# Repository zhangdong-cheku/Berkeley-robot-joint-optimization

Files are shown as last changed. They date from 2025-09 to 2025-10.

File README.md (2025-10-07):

# Berkeley robot joint optimization - 高性能摆线减速器

##  点击图片查看视频
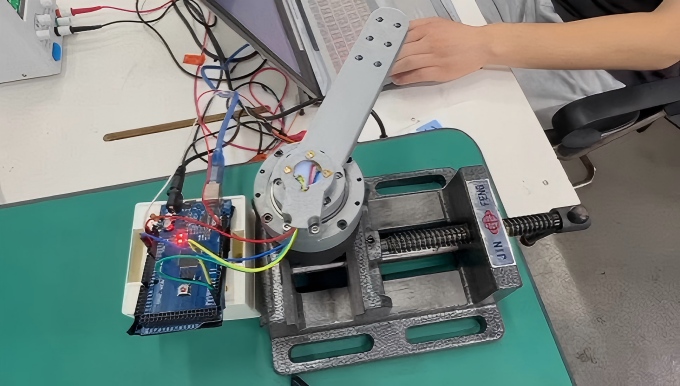
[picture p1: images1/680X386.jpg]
青潮智科 (UntHub) 视频介绍 (https://www.bilibili.com/video/BV1g6nszREnb)


---

##  项目概述
**CycloidalReducer100** 是伯克利开源机器人项目中的摆线传动方案，进行深度优化与复刻的高精度减速器。它采用经典的摆线针轮啮合原理，具备**高扭矩密度、零背隙、长寿命**等优点，专为机器人关节、精密转台、自动化设备等对传动性能要求极高的场景设计。

项目目标是为开源社区和工业界提供一个可靠、高性能、易于获取的减速器解决方案，推动先进机器人的创新与普及。

---

##  核心特性
*   **高精度与零背隙**：精密的齿形优化与制造工艺，确保传动平稳，定位精准。
*   **高扭矩密度**：紧凑的结构设计，在狭小空间内实现大的输出扭矩。
*   **高刚性 & 抗冲击**：多齿同时啮合，承载能力强，适用于高动态负载场景。
*   **长寿命与高可靠性**：关键部件采用高强度轴承钢并经特殊热处理，耐磨性好。
---

##  技术规格
| 参数 | 数值/描述 | 单位/备注 |
| :--- | :--- | :--- |
| **型号** | Berkeley robot joint | - |
| **额定输出扭矩** | 100 | N·m |
| **峰值扭矩** | 300 | N·m |
| **减速比** | 11, 17, 23, 29, 35, 43, 59, 71, 87 | 可选 |
| **背隙** | ≤ 5 | arcmin (标准型) |
| **输入转速** | ≤ 3000 | rpm |
| **效率** | ≥ 90% | - |
| **重量** | ≈ 8.5 | kg |
| **防护等级** | IP65 | - |
| **安装方式** | 法兰安装 | - |

---

## 项目展示

### 1. 整体外观
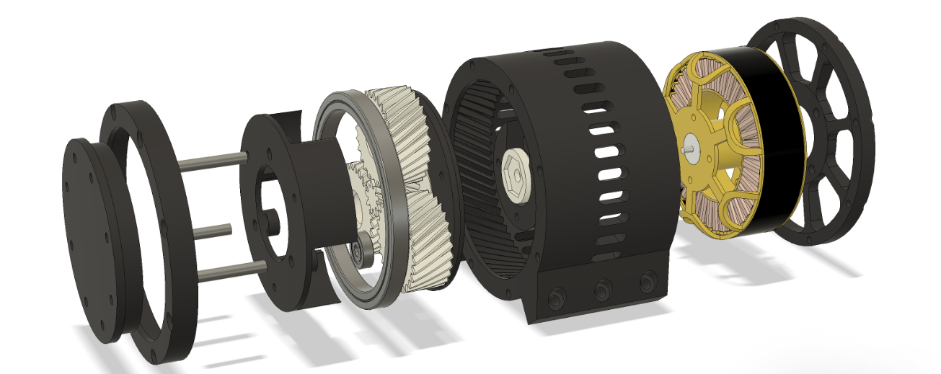
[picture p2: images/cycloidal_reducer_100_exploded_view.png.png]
Berkeley robot joint optimization爆炸视图
<!-- 请替换为实际图片路径，并提供 alt 文本 -->
*图：Berkeley robot joint optimization 整机装配体，展现了紧凑的设计与精湛的工艺。*

 <!--2. 爆炸视图-->
 <!--![爆炸视图](images/cycloidal_reducer_100_exploded_view.png.png) --><!-- 请替换为实际图片路径 -->
 <!--*图：减速器爆炸视图，清晰展示所有内部零件及其装配关系。*-->

 <!--3. 应用场景-->
<!--  ![机器人关节应用](images/reducer_in_robot_arm.jpg)--> <!-- 请替换为实际图片路径 -->
<!-- 图：CycloidalReducer100 应用于六轴工业机器人关节模组。*-->

---

##  安装与使用

### 环境准备
*   3D 建模软件（如 **SolidWorks**, **Fusion 360**）用于查看模型。
*   机械装配工具（扭矩扳手、螺丝刀套装等）。

### 安装步骤
1.  **获取模型**：

模型文件位于 `models/` 目录下（提供 STEP 和 SLDPRT 格式）。

2.  **机械安装**：
*   确保安装面平整清洁。
*   使用规定的螺栓（如 M8）和扭矩（**80 N·m**）紧固。
*   保证输入轴与驱动电机轴、输出轴与负载轴的**同轴度**（建议 ≤ 0.03mm）。

3.  **润滑**：
*   首次使用前，加注适量的 **ISO VG 220** 工业齿轮油至油窗中线。
*   每运行 2000 小时或一年后更换润滑油。

## 加入交流群
扫一扫，加入QQ群，一起手搓机器人

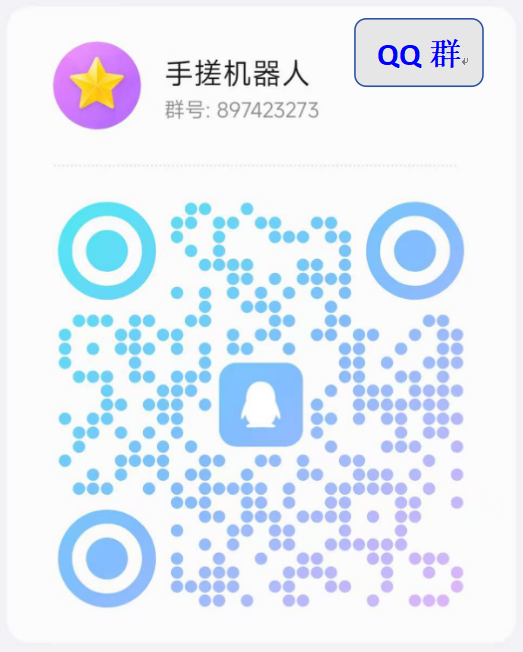
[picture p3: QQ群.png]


---

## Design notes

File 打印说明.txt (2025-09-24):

1.3D打印机推荐：：拓竹系列参数的匹配性。
2.打印材料：采用pla3D材料。
3.打印参数，使用拓竹系列打印机默认配置，填充密度50%-60%，摆线轮、行星轮可填充至70%，太阳轮可填充至80%。

***注意：solidworks文件导出，以step格式导出，减少层纹出现，减少摩擦，可购买（虎头0号润滑脂）提高降速机寿命。

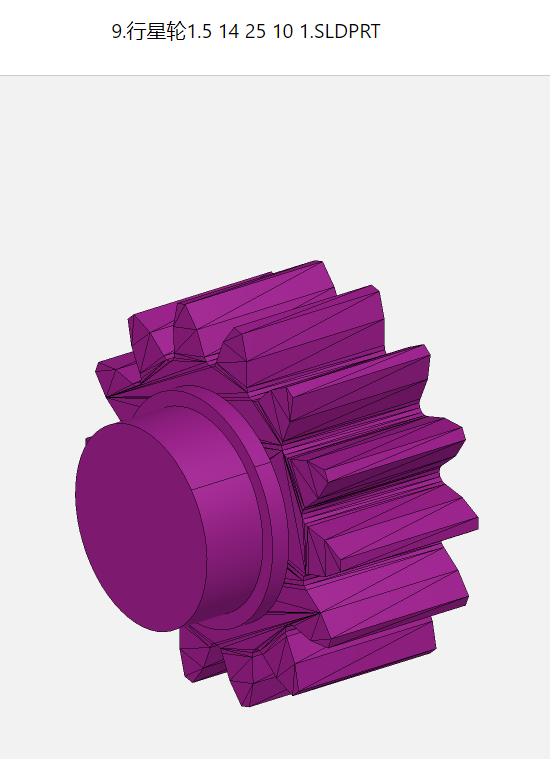
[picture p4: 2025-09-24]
images/8.行星轮1.5 14 25 10 1.png

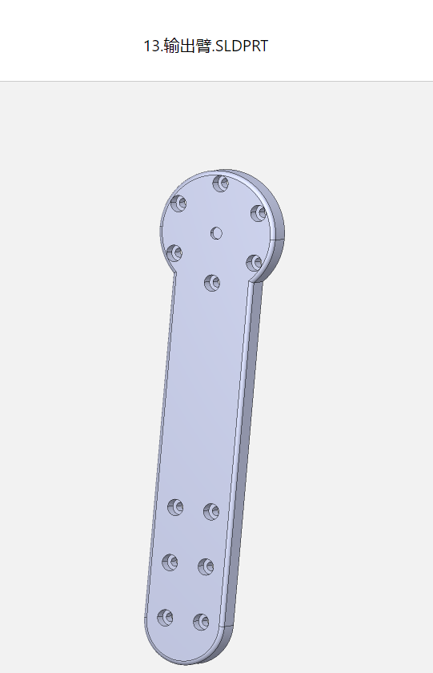
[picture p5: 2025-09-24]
images/12.输出臂.png

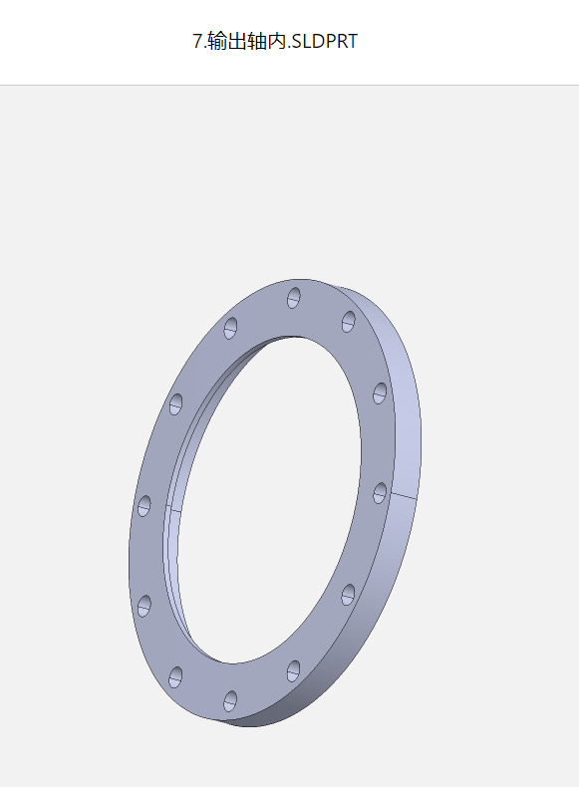
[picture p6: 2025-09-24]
images/6.输出轴内.png

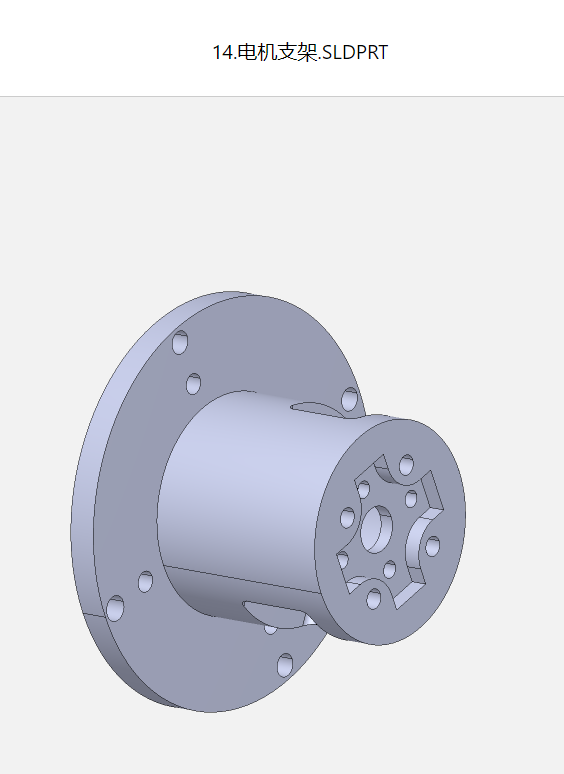
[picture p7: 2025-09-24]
images/13.电机支架.png

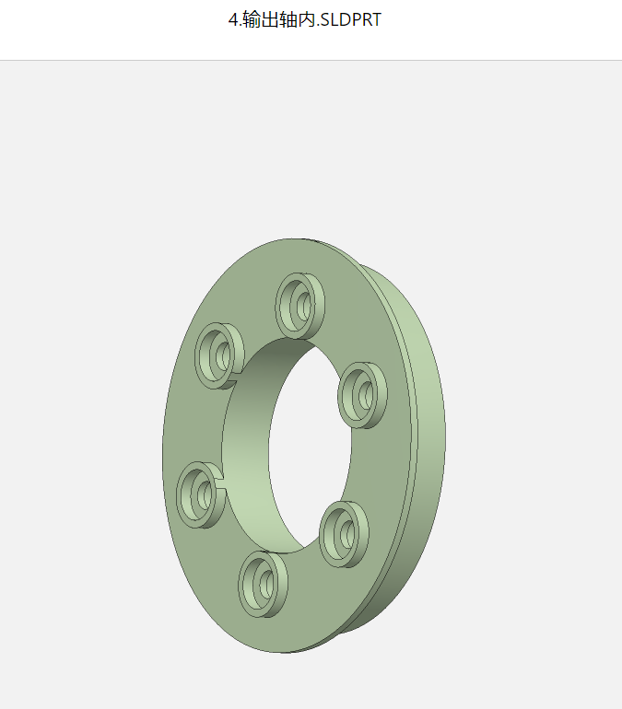
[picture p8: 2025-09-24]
images/3.输出轴内.png

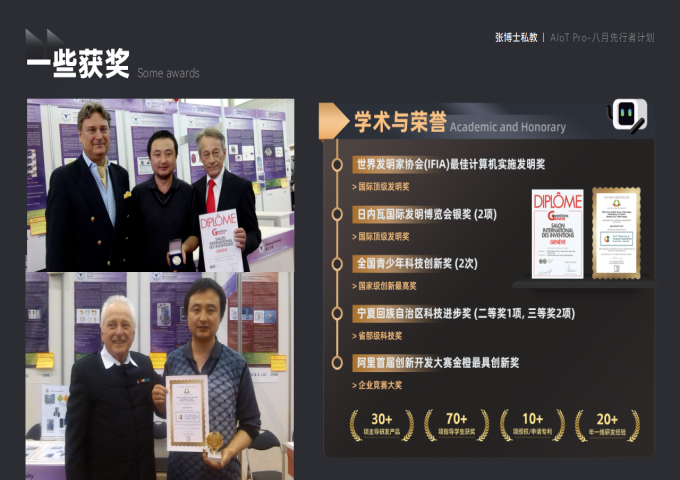
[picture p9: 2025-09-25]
images/team/250c74cfa8658368c13a1646a05376d6.png

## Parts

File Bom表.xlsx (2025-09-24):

70.115行星摆线减速机BOM/结构部分
名称 | 型号 | 数量 | 单价/元 | 总价 | 备注 | 链接
轴承 | MR106-2RS | 13 | 1.44 | 18.72 | 内径8外径10mm两侧密封 | https://detail.tmall.com/item.htm?id=850288392637&skuId=5639536048009&spm=a21m98.27004841
轴承 | MR106-2RS | 5 | 1.84 | 9.2 | 内径12外径18mm两侧密封 | https://detail.tmall.com/item.htm?abbucket=9&id=672836796497&skuId=5017505094887
轴承 | 6809ZZ | 2 | 3.11 | 6.22 | 两侧密封 | https://detail.tmall.com/item.htm?abbucket=8&id=695287603935&ns=1&skuId=5102438922481
螺钉 | M3*55mm | 10 | 0.3 | 3 |  | https://detail.tmall.com/item.htm?abbucket=8&id=654819932601
螺钉 | M3*25mm | 50 | 0.066 | 3.3 |  | https://detail.tmall.com/item.htm?abbucket=8&id=654819932601&skuId=5014407101291
螺钉 | M3*16mm | 100 | 0.05 | 5 |  | https://detail.tmall.com/item.htm?abbucket=8&id=654819932601&skuId=4732319681183
螺钉 | M3*8mm | 100 | 0.04 | 4 |  | https://detail.tmall.com/item.htm?abbucket=8&id=654819932601&skuId=4732319681175
热熔螺母 | M3*4*5 | 100 | 0.13 | 13 |  | https://item.taobao.com/item.htm?id=593581996419&skuId=4189077672129
六角铜隔离柱 | M4*12 | 10 | 0.333 | 3.33 |  | https://detail.tmall.com/item.htm?abbucket=8&id=645528391157&skuId=4641513876088

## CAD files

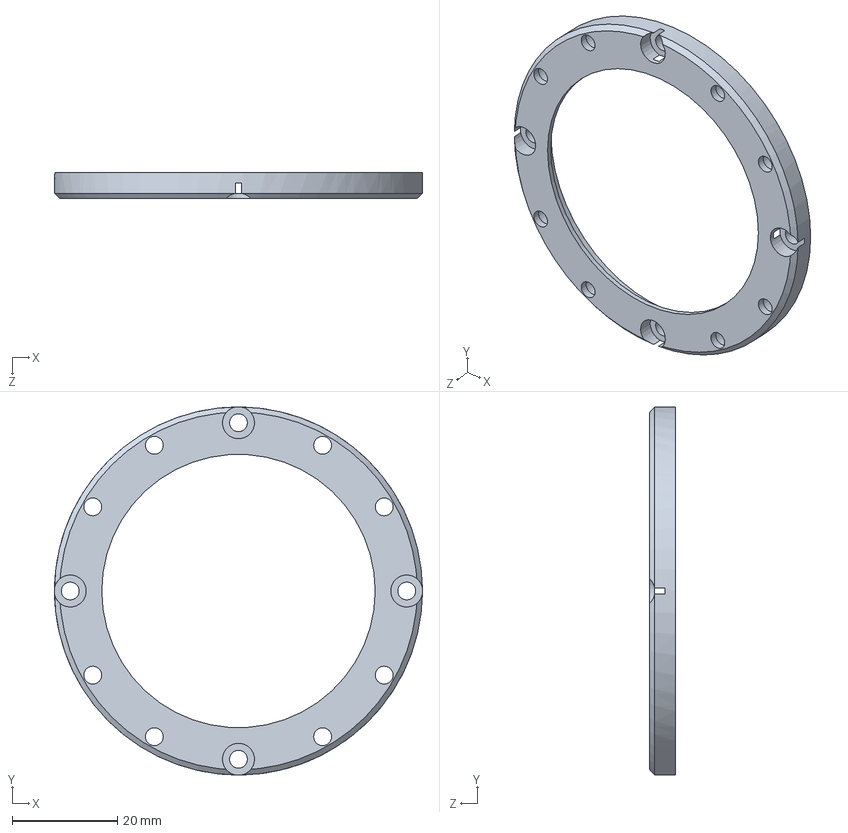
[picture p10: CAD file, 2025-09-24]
STL/5.针齿壳外.SLDPRT
70.0 x 70.0 x 5.00 mm

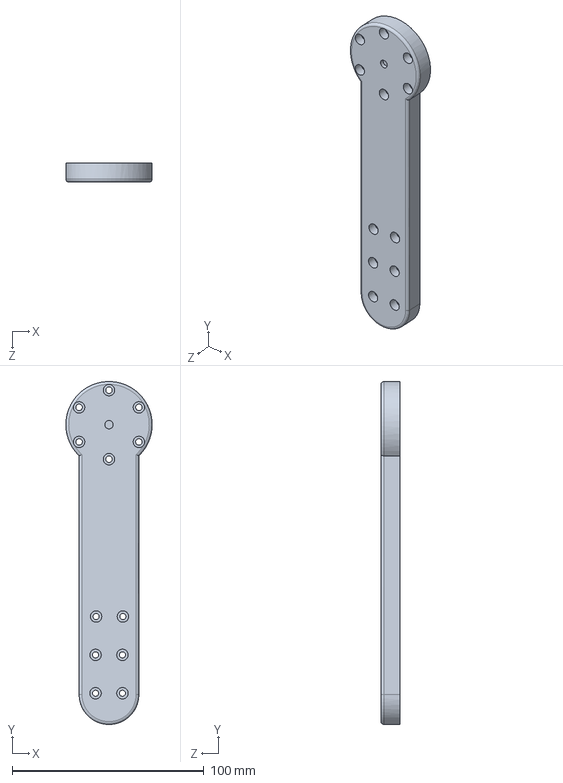
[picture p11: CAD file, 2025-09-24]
STL/13.输出臂.SLDPRT
45.0 x 178.8 x 10.0 mm

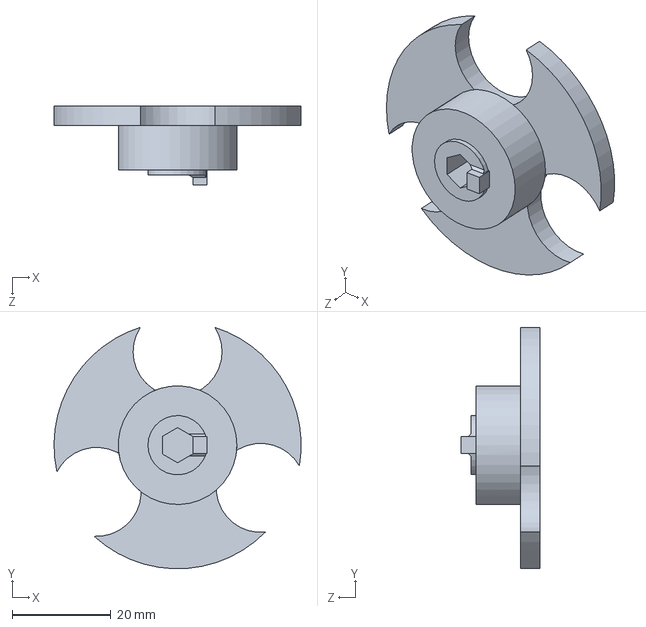
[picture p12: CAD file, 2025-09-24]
STL/8.行星支架.SLDPRT
50.0 x 48.8 x 16.0 mm

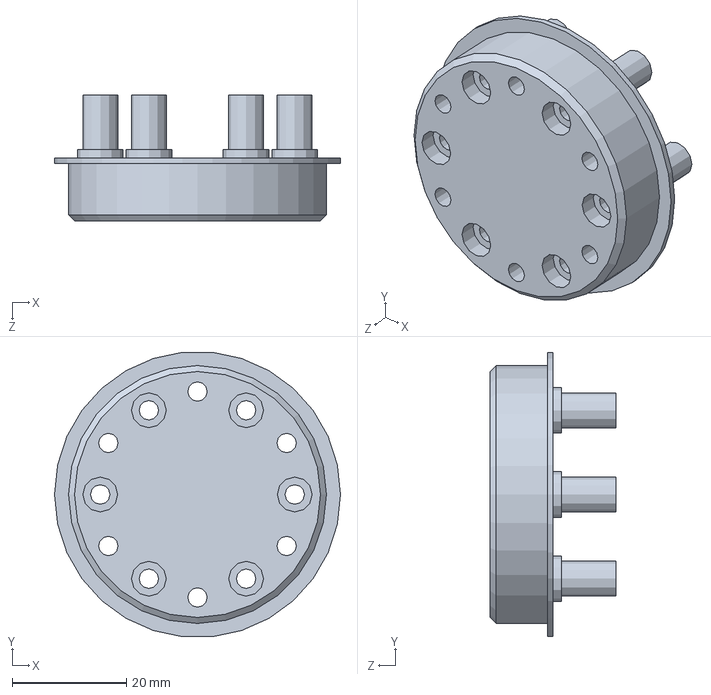
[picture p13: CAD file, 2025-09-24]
STL/1.输出轴外.SLDPRT
50.0 x 49.7 x 22.0 mm

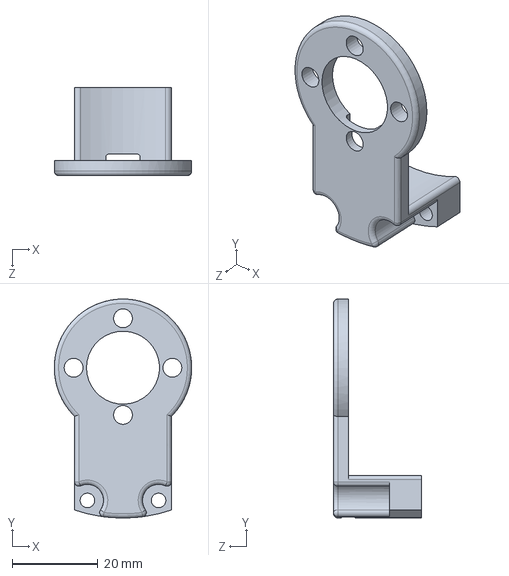
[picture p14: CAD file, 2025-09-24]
STL/12.角度支架.SLDPRT
32.0 x 51.0 x 20.5 mm

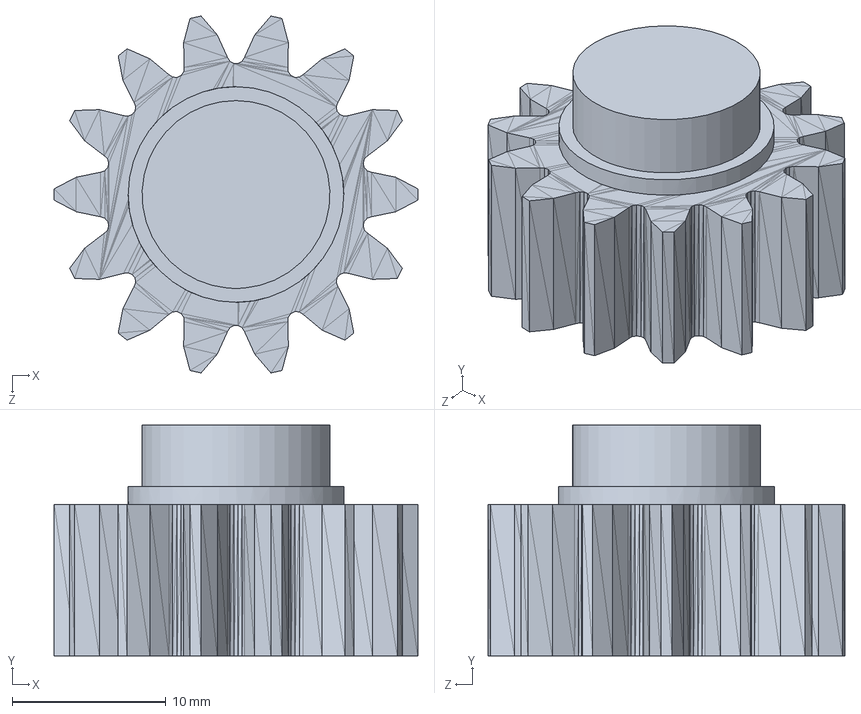
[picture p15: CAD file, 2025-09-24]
STL/9.行星轮1.5 14 25 10 1.SLDPRT
23.6 x 15.0 x 23.2 mm

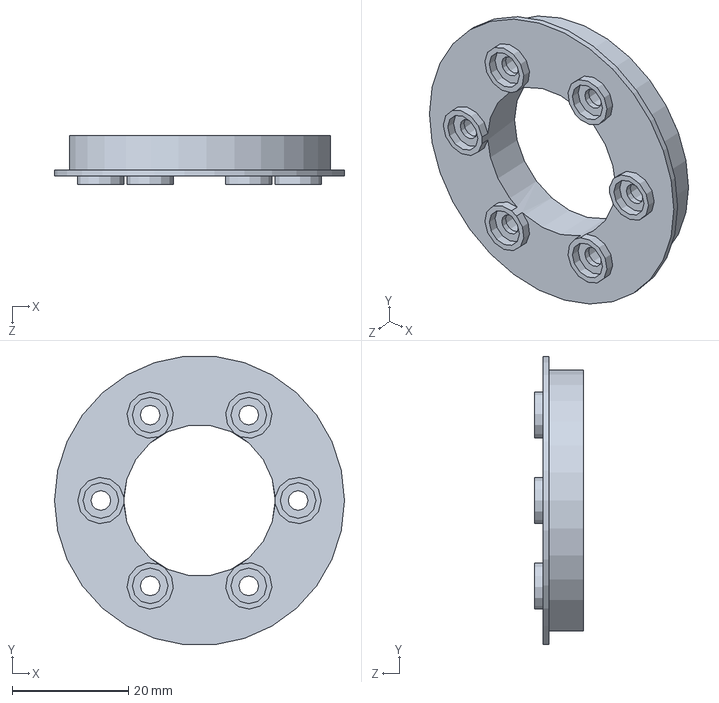
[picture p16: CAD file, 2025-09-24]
STL/4.输出轴内.SLDPRT
50.0 x 49.7 x 8.50 mm

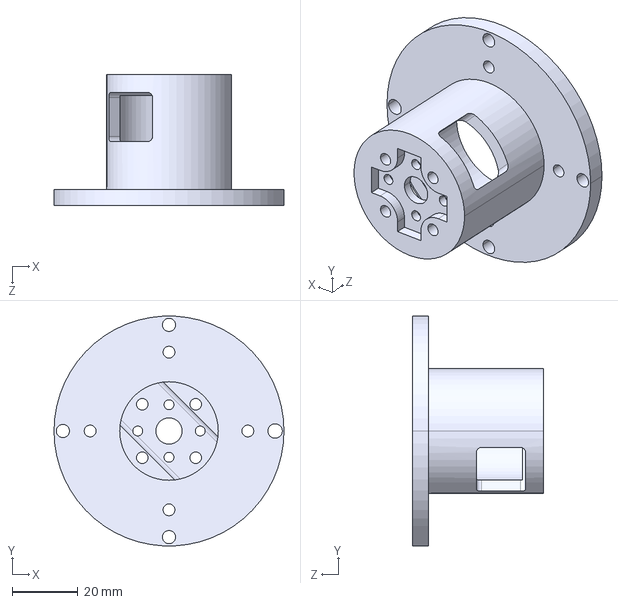
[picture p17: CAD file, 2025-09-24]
STL/14.电机支架.STEP
70.0 x 69.9 x 40.0 mm

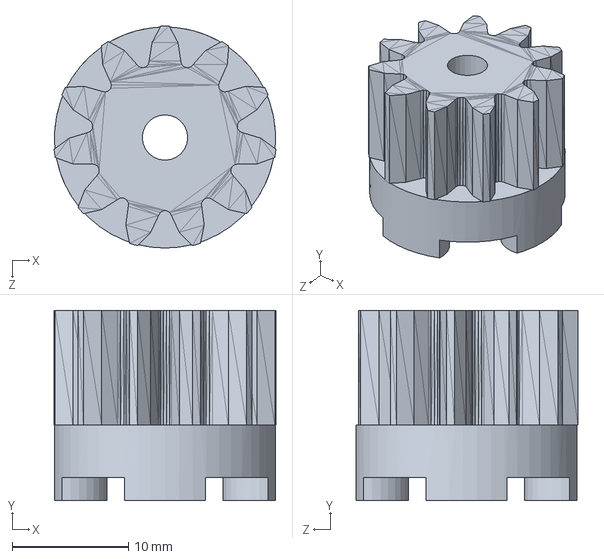
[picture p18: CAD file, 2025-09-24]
STL/10.太阳轮1.5 11 25 10 4.SLDPRT
19.1 x 16.3 x 19.1 mm

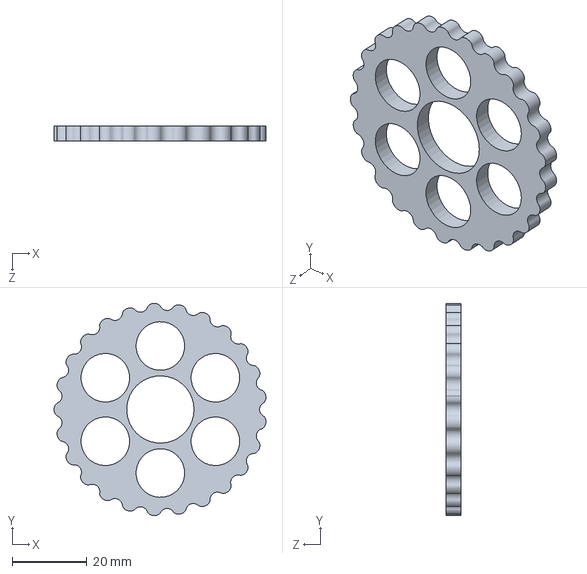
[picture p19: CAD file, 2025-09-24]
STL/6.摆线齿轮.SLDPRT
56.7 x 56.8 x 4.10 mm

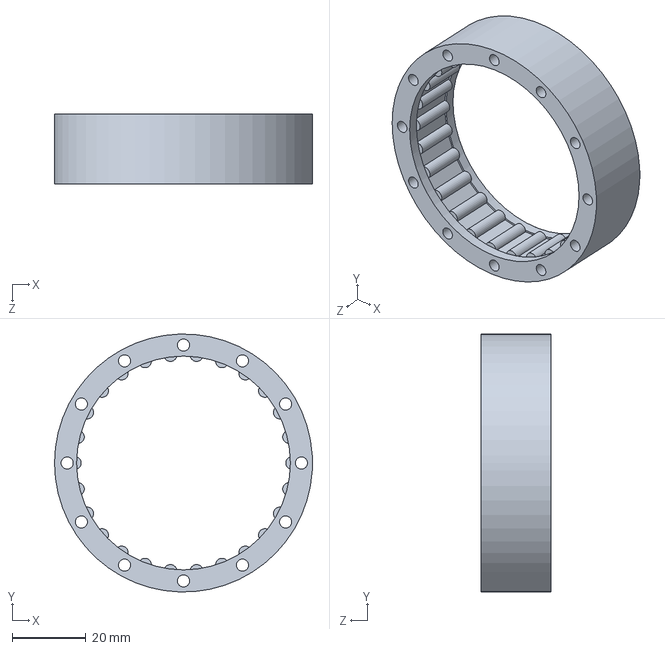
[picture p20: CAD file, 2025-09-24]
STL/3，摆线针齿壳,2个.SLDPRT
70.0 x 70.0 x 19.0 mm

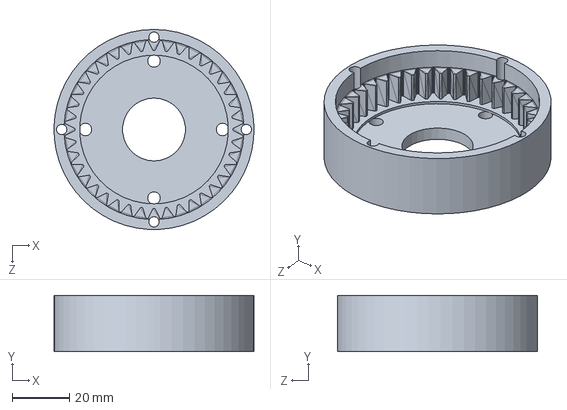
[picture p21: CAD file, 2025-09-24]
STL/11.行星齿圈.SLDPRT
70.0 x 19.7 x 70.0 mm

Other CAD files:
STL/7.输出轴内.SLDPRT
STL/14.电机支架.SLDPRT

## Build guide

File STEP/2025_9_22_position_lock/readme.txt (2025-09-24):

代码功能
该代码实现了一个基于mega2560、 AS5600 角度传感器和 双向电调的闭环控制系统，核心功能是通过 PID 算法控制电机转动到目标角度，并支持通过串口进行远程控制。具体功能包括：
传感器数据采集：通过 I2C 读取 AS5600 角度传感器的原始角度，经中值滤波处理后得到稳定的当前角度，并计算实时转速。
PID 闭环控制：根据当前角度与目标角度的偏差，通过 PID 算法计算控制量，转换为电调脉宽信号，控制电机正转 / 反转，使角度稳定到目标值。
状态管理：支持电机启动 / 停止、目标角度设置状态切换。
串口交互：通过串口接收命令（如设置目标角度、调整 PID 参数、停止电机等），并实时反馈系统状态（当前角度、目标角度、运行状态等）。
性能监控：统计并报告系统运行性能（每秒主循环次数、采样次数），用于调试和优化。

模块名称				核心函数 / 组件						作用描述
传感器模块		readAngle()、medianFilter()			读取 AS5600 角度传感器数据，通过中值滤波减少噪声，提供稳定的角度输入。
控制算法模块		pidControl()、calcAngleDiff()			实现 PID 控制逻辑，计算角度偏差（处理 360 度循环），输出控制量到电调。
电机驱动模块		Servo esc、setTarget()、stopMotor()		控制 ESC 电调，将 PID 输出转换为脉宽信号，实现电机正转 / 反转 / 停止。
串口通信模块		parseCommand()、sendStatus()		解析串口命令（如设置角度、调整 PID），实时反馈系统状态（角度、目标、PID 输出）。
系统调度模块		loop()中的任务调度逻辑			按时间间隔执行采样、PID 计算、状态反馈等任务，确保系统实时性。
统计模块			reportStats()、Stats结构体			统计主循环次数、采样次数，每秒输出一次，监控系统运行性能。

┌───────────────┐
│   setup()初始化  │
│  - 串口/I2C初始化 │
│  - 电调初始化    │
│  - 设置初始目标  │
└───────┬───────┘
        ▼
┌───────────────┐
│   loop()主循环   │
│  (循环执行以下任务) │
├───────┬───────┤
│  采样任务       │ 检查是否到达采样间隔 → 读取原始角度 → 滤波 → 计算转速
├───────┼───────┤
│  PID控制任务    │ 检查是否到达PID间隔 → 计算角度偏差 → 执行PID计算 → 输出脉宽到电调
├───────┼───────┤
│  串口命令解析    │ 检查串口是否有数据 → 解析命令（STOP/ANGLE等）→ 执行对应操作
├───────┼───────┤
│  状态反馈任务    │ 检查是否到达反馈间隔 → 发送当前角度/目标/状态到串口
├───────┼───────┤
│  性能统计任务    │ 检查是否到达统计间隔 → 计算并输出每秒循环/采样次数
└───────┴───────┘
        │
        ▼ (循环往复)

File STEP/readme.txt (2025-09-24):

2025_9_22_position_lock  包含使用Mega2560+双向电调+AS5600磁编码器+双向电调的位置闭环方案
data记录了电机重复定位精度的测试数据

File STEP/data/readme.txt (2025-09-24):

data是使用百分表测量的电机重复定位精度数据
_.py程序用于绘制data测试数据曲线绘制
boc plot.py绘制箱线图+散点图；Histogram.py用于绘制直方图；Line Chart.py折线图；
Regression Plot.py用于绘制线性回归图；Scatter Plot.py用于绘制散点图

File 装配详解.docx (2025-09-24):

1. 准备材料工具。
  1.1， MR106-2RS轴承13个，MR106-2RS轴承五个，6809ZZ轴承两个。
  1.2， 螺丝M3*55mm4枚，M3*25mm6枚，M3*16mm8枚，M3*8mm4枚，热熔螺母M3*4*5mm,六角铜螺柱。
  1.3， 六角扳手，电烙铁。
2. 装配摆线减速机

2.1，把M3*4*5mm热熔螺母用电烙铁分别熔如以下对应孔中，共用22枚，分别是输出轴内外圈，摆线针齿壳内外圈，行星轮外齿圈

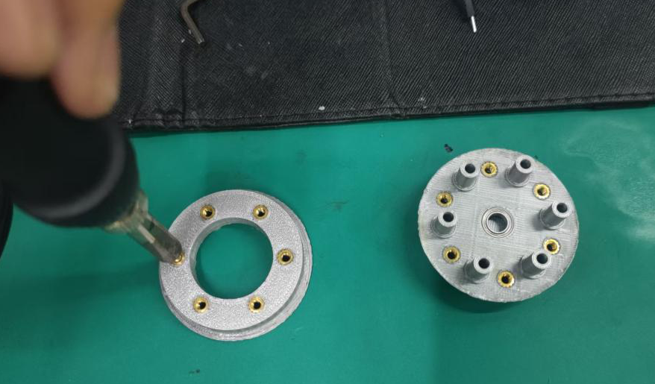
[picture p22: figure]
1e814db55ad14a1e16fdd88a30f728ab

，该图外圈四孔不用熔铜螺母。

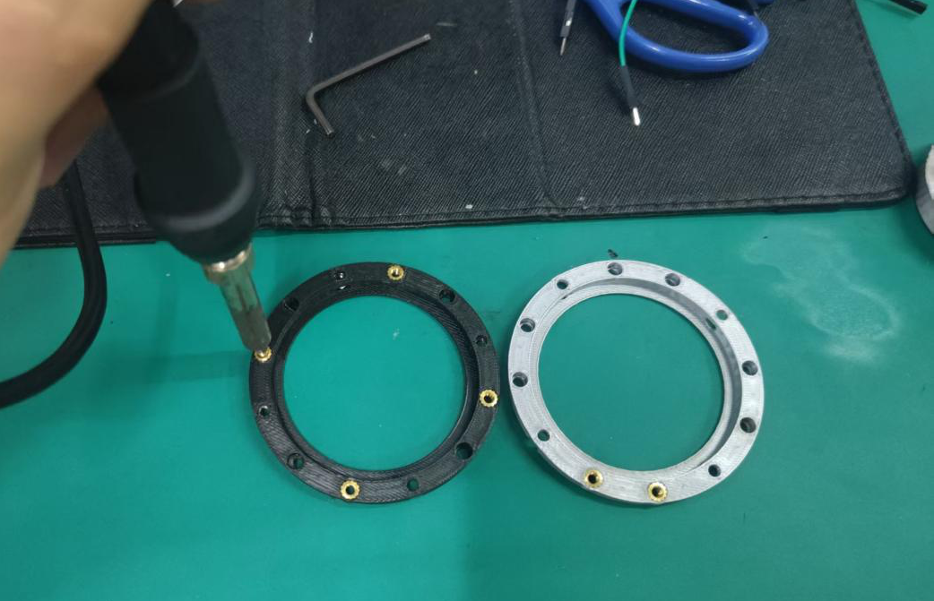
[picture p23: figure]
e10687630e68023cac5dfa58d4526589
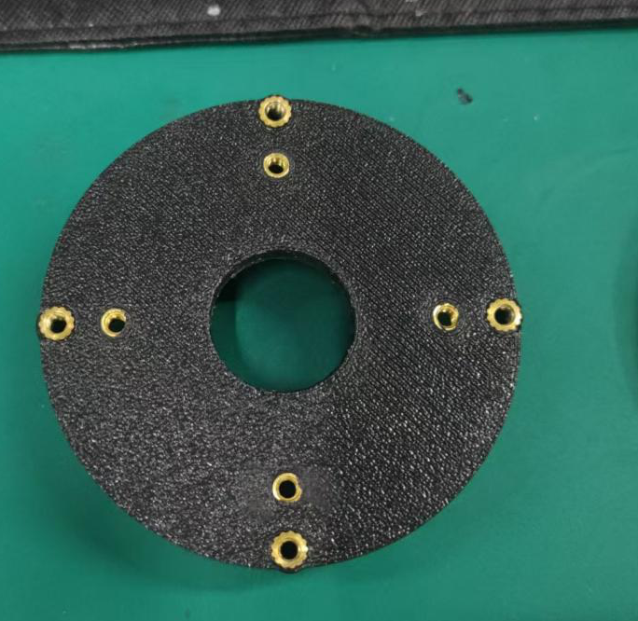
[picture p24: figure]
f3eedf5e0502a8d263884dade0193f82

2.2开始装配内侧部分

a.两个摆线轮都压入一个内12mm外18mm的轴承，输出轴外中间压入一个内6mm外10mm的轴承。

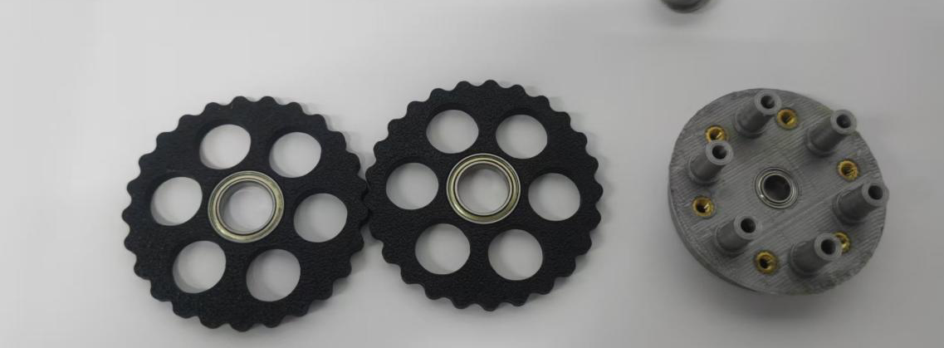
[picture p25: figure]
39ddc875ff0e8b0403d027cafaec0fe2

b.分准备6个轴承隔圈，12个内6mm外10mm的轴承。

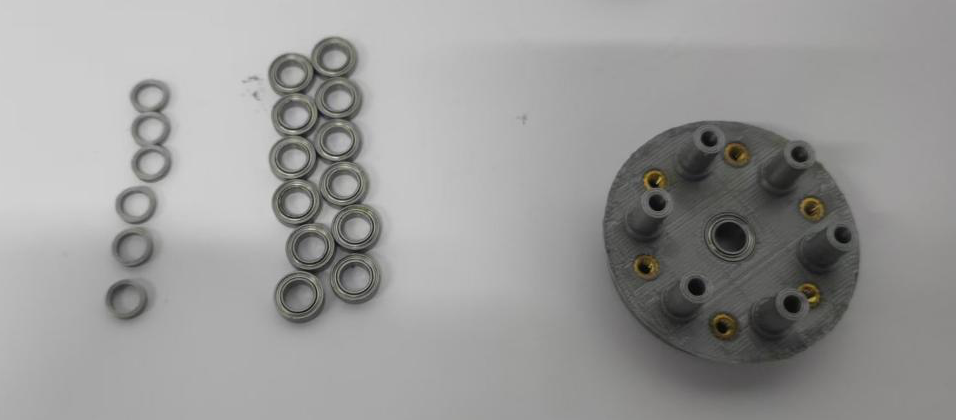
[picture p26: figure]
22b61b534f746d2a04558c9fa61d7e06

C.6根柱子都以轴承，轴承隔圈，轴承的顺序分别逃入。

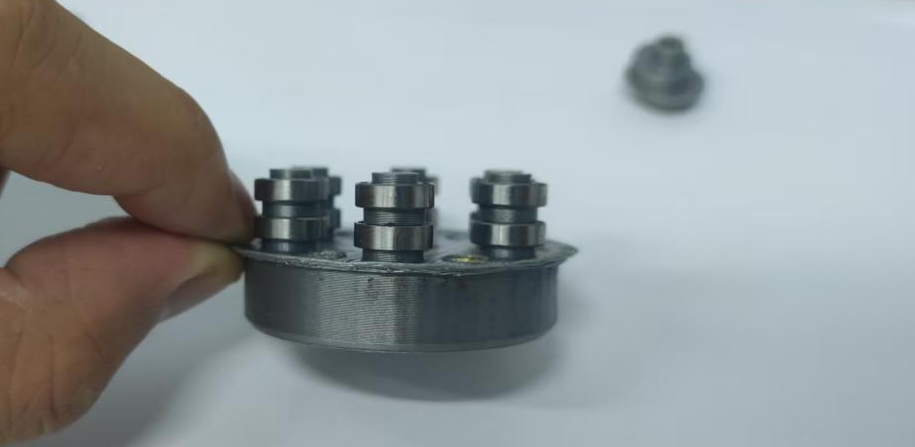
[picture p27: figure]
f7233feee3cec1f91c2dcf5774cf7d7a

d.先套入第一个摆线轮。

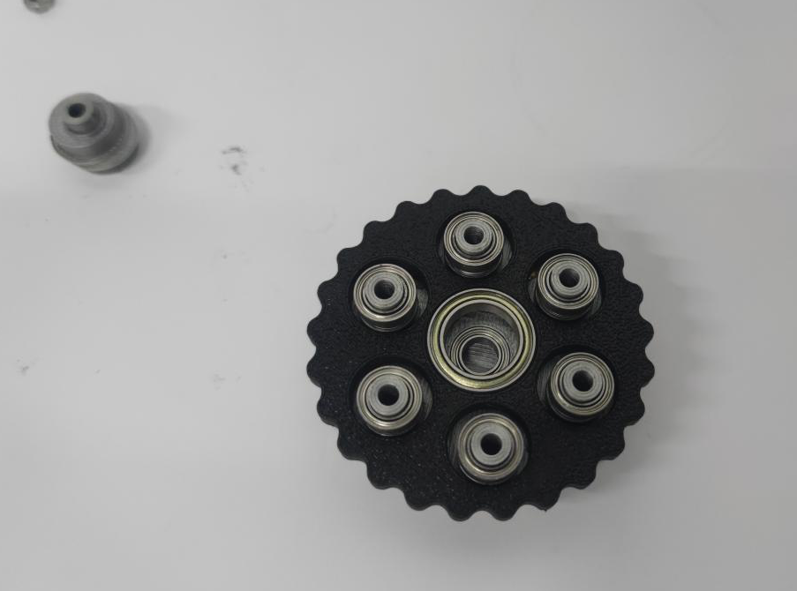
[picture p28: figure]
595812c27d24b6bab9e6424a34d45936

e.放入偏心轴

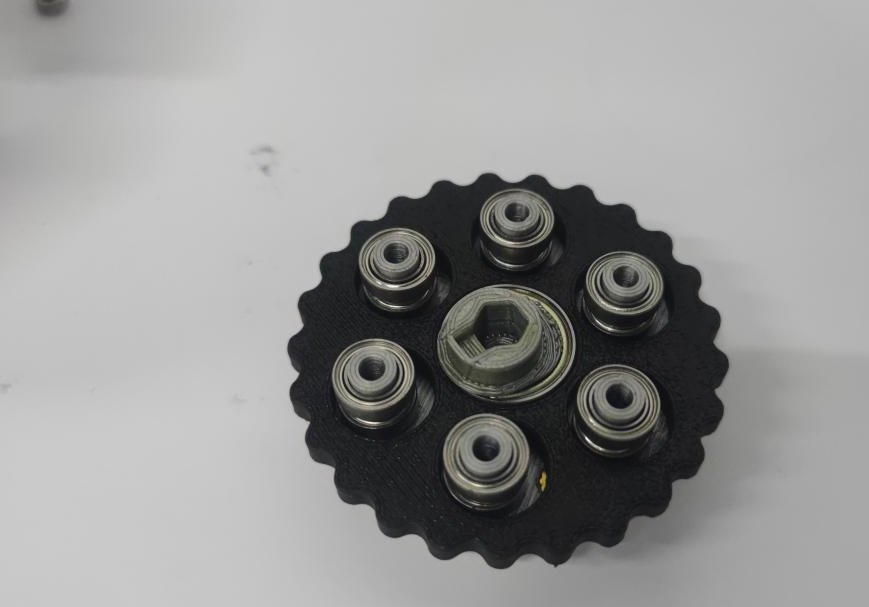
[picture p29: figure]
78cd282df0830e27bd78bfba29f8b668

f.套入第二个摆线轮，后加盖输出轴内的部分。

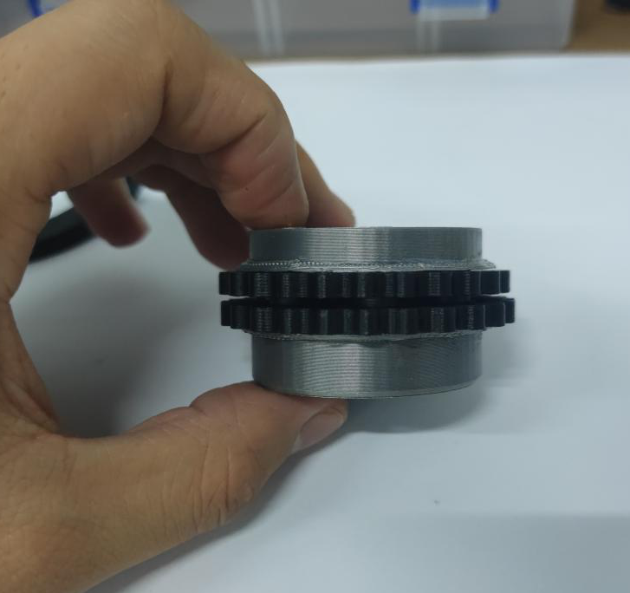
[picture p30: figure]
2e69180ab974498d88790b558e3e4ecf

g.准备6枚M3*25mm螺丝，从输出轴外侧，对应孔位一一拧紧。

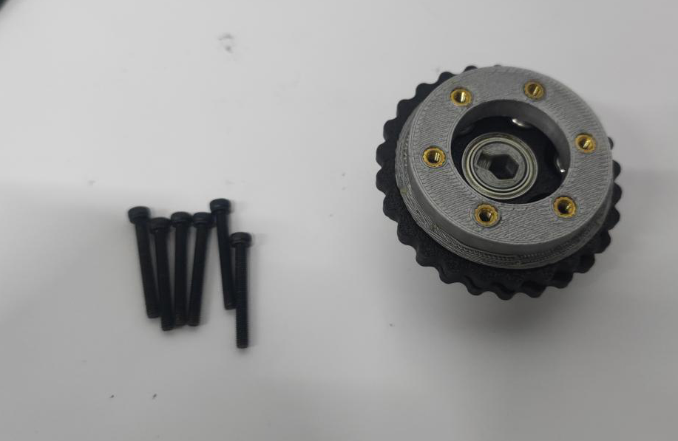
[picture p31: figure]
60061f5334791f9be2253d0d5d2dbf76
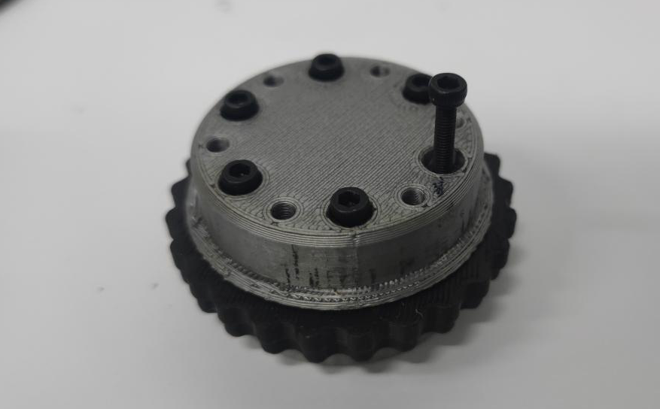
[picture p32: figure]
4f38c656242a4ce989eb827be602484b

2.3摆线减速机整体装配。

a.按图准备各个零件名称依次为，针齿壳内圈，针齿壳外圈，摆线减速机内侧部分，两枚6809ZZ轴承，针齿外壳。

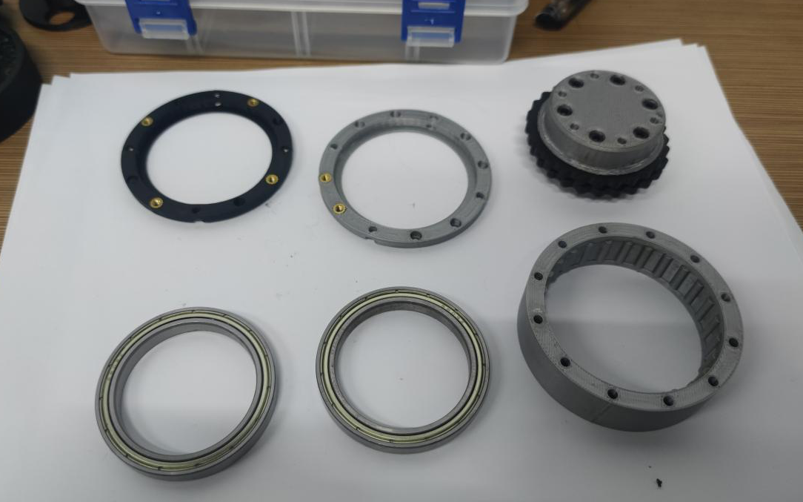
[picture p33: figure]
8a5d4aa028e60efdbb4ff494d6c412cb

b.先将一枚6809ZZ轴承按入针齿外壳一段。

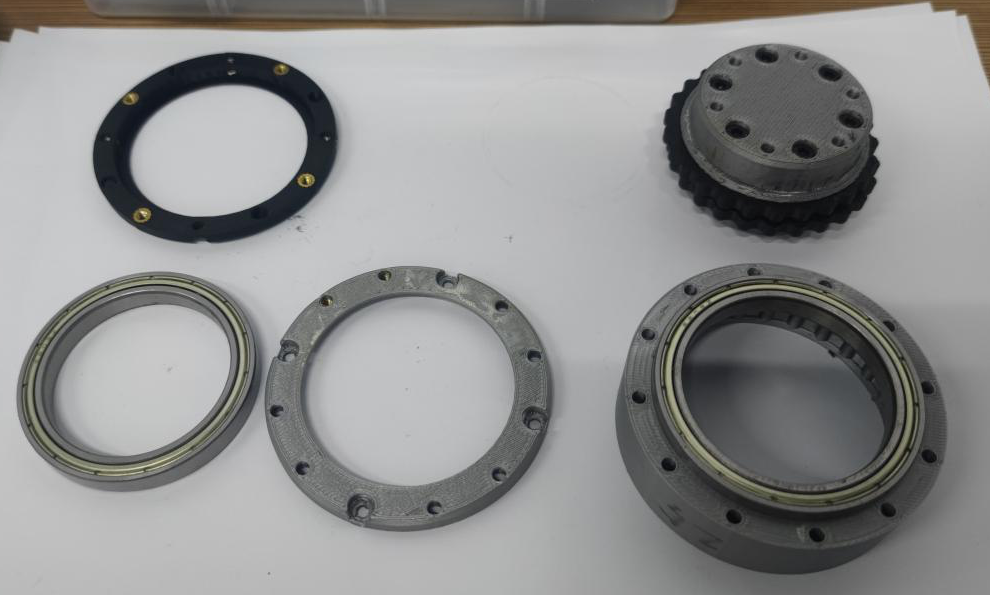
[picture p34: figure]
2b48bf26a4b5f4941c681565c6d90ee2

C.将针齿壳外圈带入刚刚装好轴承一侧，并对号孔位。

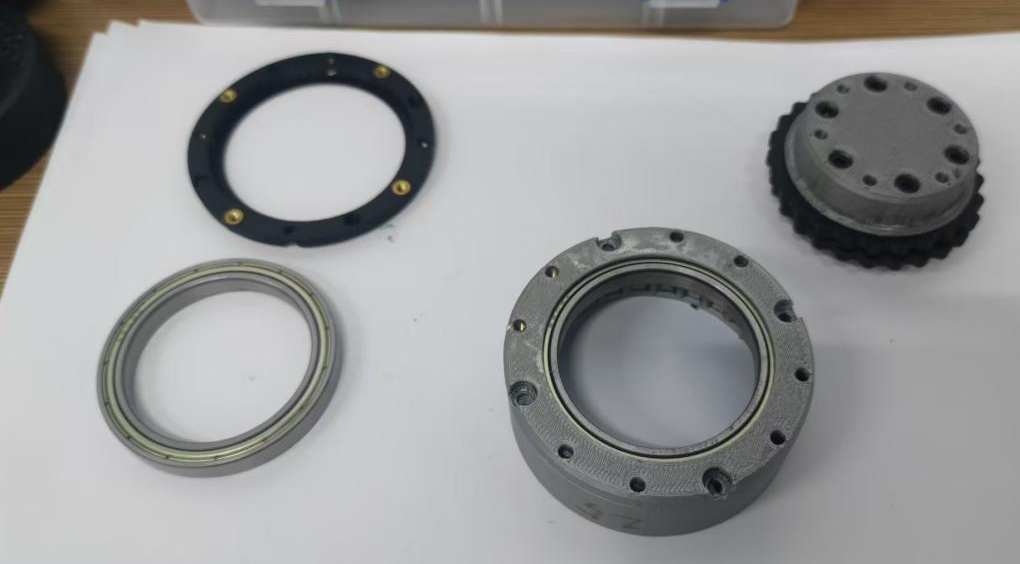
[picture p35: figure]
77bddb97634eb520371935b9fa53331b

d.将摆线轮内侧，从壳体另一段放入。

e.分别将再将轴承，针齿壳外圈依次安装。

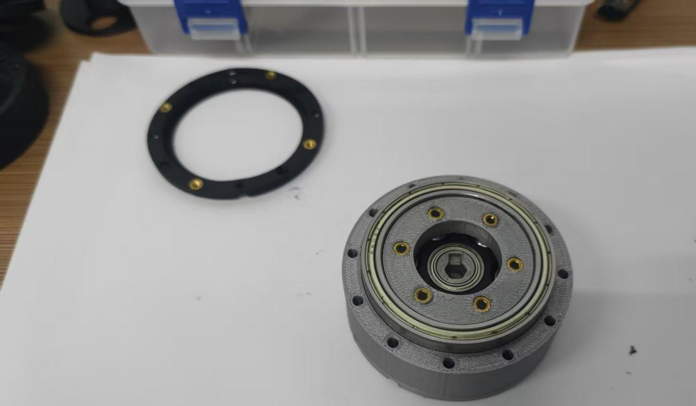
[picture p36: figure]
4ed13d58dee8956d573bd30073e22ddd

3. 装行星轮部分并合并安装。

3.1准备三枚行星轮，行星支架，三枚内12外18mm轴承，一枚六角铜轴，四枚M3*55mm螺丝。

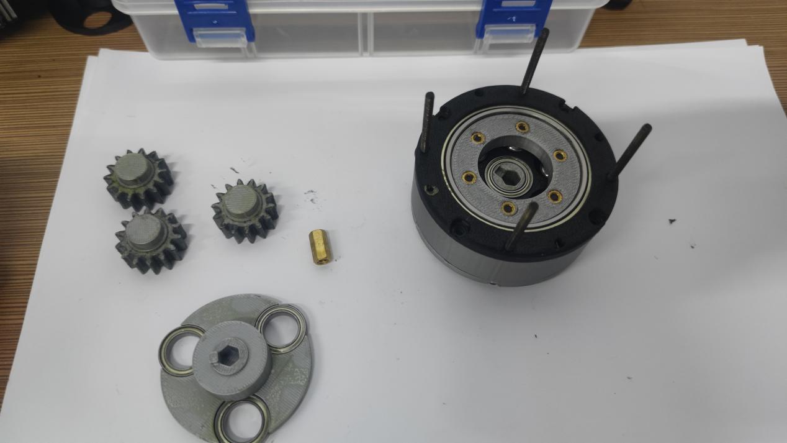
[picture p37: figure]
95819d8c6ad6ee73691f63c5614cc7db

a.将六角铜轴放入行星支架孔位内，将M3*55mm螺丝从输出轴外侧孔内插入。

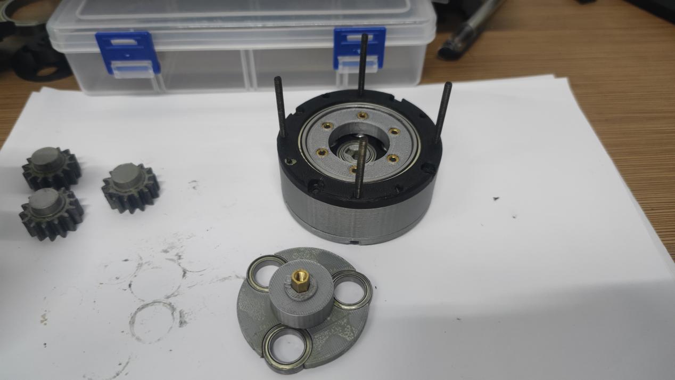
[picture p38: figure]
61b2d6589c5126fa9fe9838668da8dd6

b.将行星支架插入摆线减速机输入轴对应孔位。

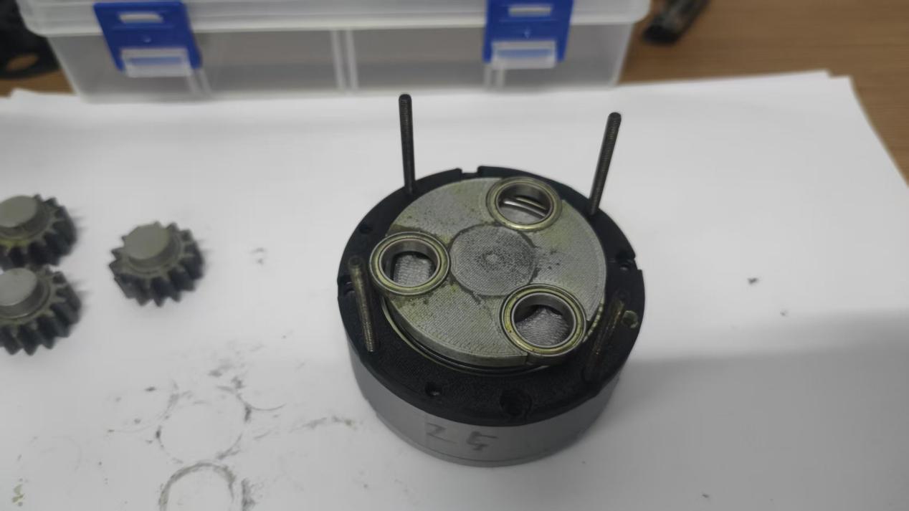
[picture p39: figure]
6768cf9cd2757a0cdc81bcab7c2d067d

c.将三枚行星轮分别放入三个孔位，并将外齿圈合盖。

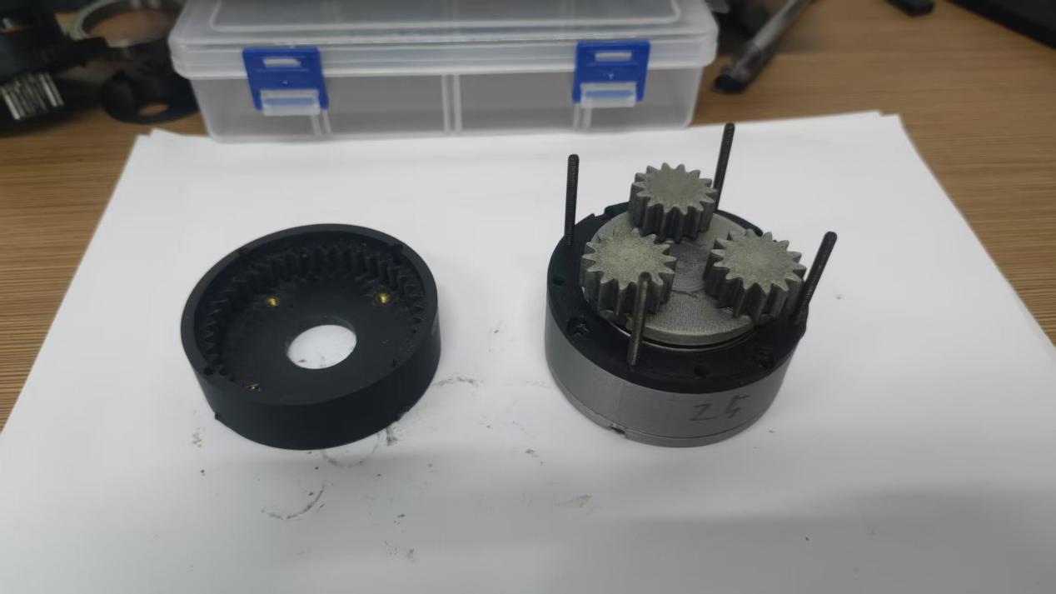
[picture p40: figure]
359c9743a7ceffbcbb7b29b8f0eaf278

3.2.将输出力臂用六枚M3*16mm固定在输出轴上。

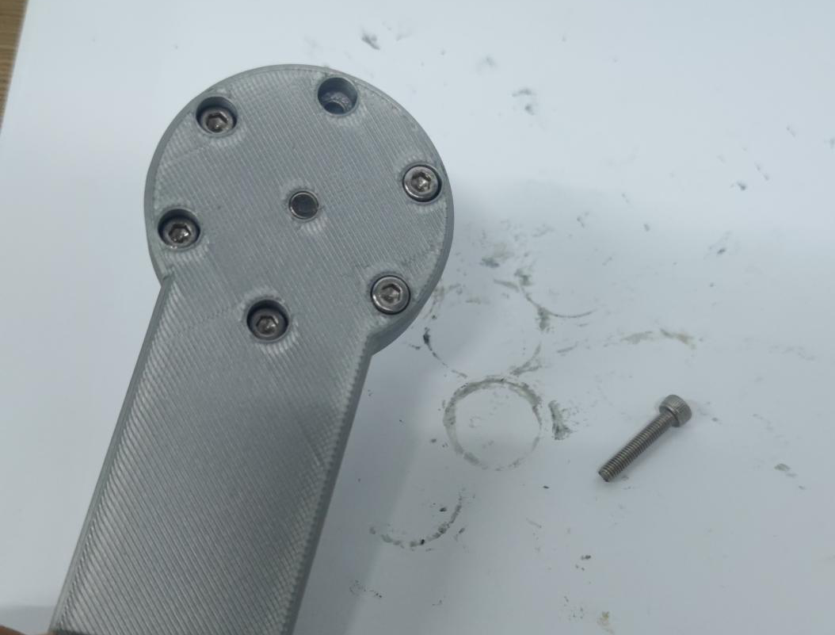
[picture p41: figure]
e21f1dd1cd413740472c43799f24251c

3.3将磁编码器用新西达的沉头螺丝固定与角度支架固定。

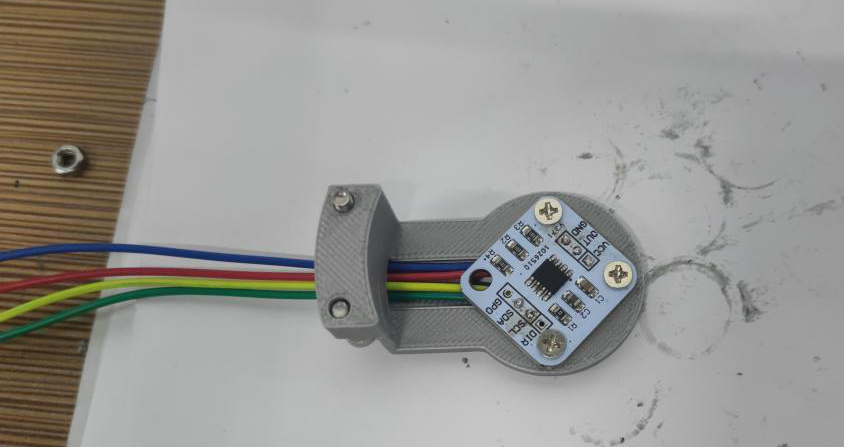
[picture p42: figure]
d231e9339a300ce9c022acf683a031bf

3.4电机轴压入太阳轮对应孔位，（注意需大一点外力因为是过盈配合）。

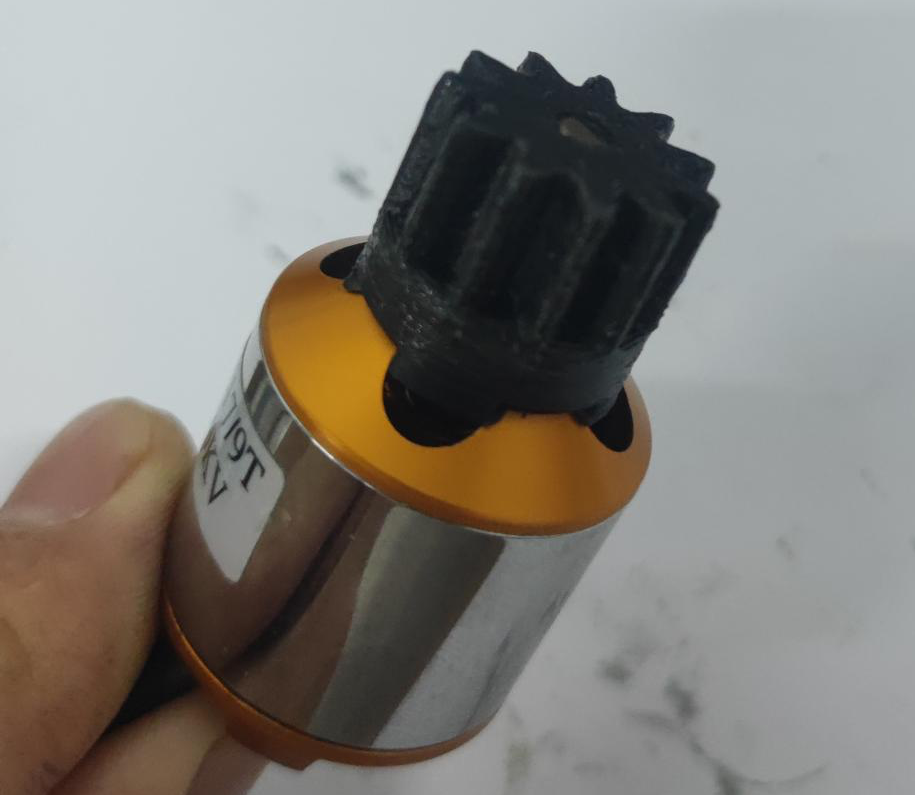
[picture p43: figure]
6bfe63a11b1eacf12b858a6a12743c94

3.5将电机固定用四枚M3*8螺丝固定电机支架上。

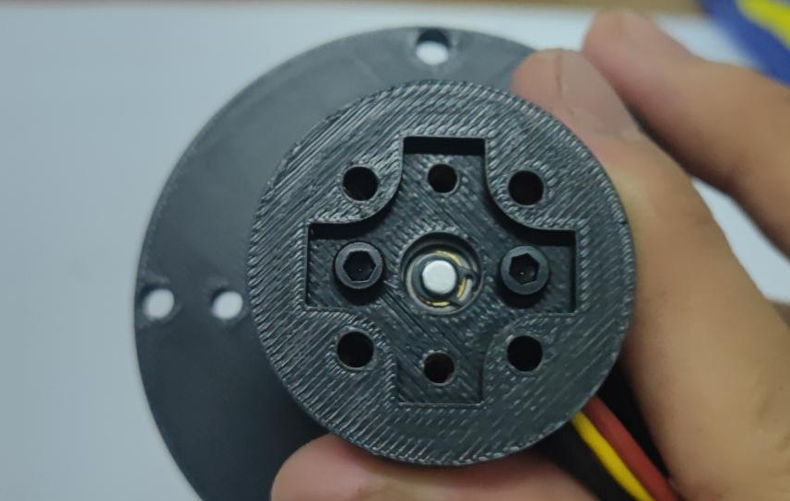
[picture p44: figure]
4cf1c79ae377a8887f56ca2d12001632

3.6将电机支架固定于行星减速机后面四个螺丝上，然后现用热熔螺母固定。

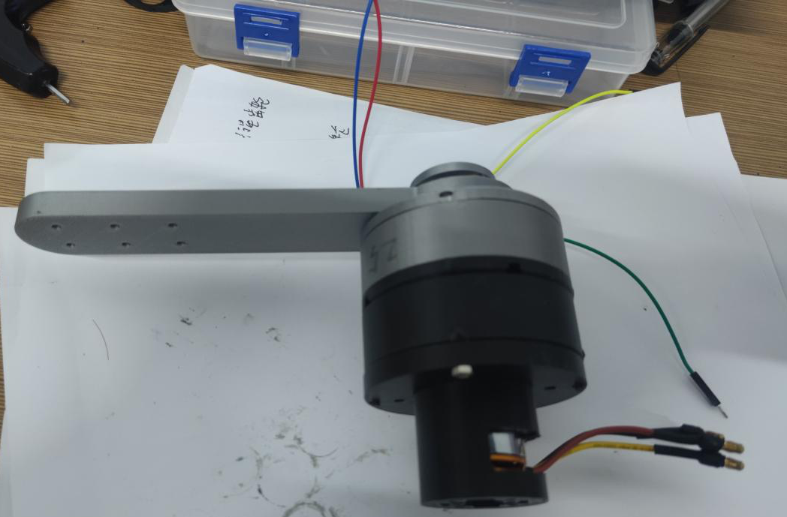
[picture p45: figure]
8dba2379ac08e64b971b19b52901dd09

4.然后整体减速结构方面装配也就完成了。

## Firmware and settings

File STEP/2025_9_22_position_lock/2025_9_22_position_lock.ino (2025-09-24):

// 引入必要的库：Wire用于I2C通信，Servo用于控制电调（本质是产生PWM信号）
#include <Wire.h>   // I2C通信库，用于与AS5600角度传感器通信
#include <Servo.h>  // 舵机/电调控制库，用于控制ESC电调

// ================== 配置参数 ==================
// AS5600磁编码器的I2C地址
#define AS5600_ADDR      0x36
// AS5600角度值寄存器地址（高字节）
#define ANGLE_REG_H      0x0E
// 配置寄存器高位地址（未直接使用）
#define CONFIG_REG_H     0x1B
// 电调信号线连接的引脚
#define ESC_PIN          9

// 电调控制信号脉宽范围（单位：微秒），不同型号电调脉宽和控制方式会有差异
#define PULSE_STOP       2200 // 电机停止的脉宽，上电时首先给电调发送停止脉宽信号，解锁电调
#define PULSE_NEUTRAL    1470 // 中立位（停止）
//电调的脉宽需要根据电调型号确定
#define PULSE_FWD_MIN    1510 // 正转起始脉宽
#define PULSE_FWD_MAX    1540 // 正转转速最大脉宽
#define PULSE_REV_MIN    1430 // 反转起始脉宽
#define PULSE_REV_MAX    1400 // 反转转速最大脉宽

// 系统安全运行的角度限制（度）
#define ANGLE_MIN        170.0f // 最小允许角度
#define ANGLE_MAX        350.0f // 最大允许角度
#define ANGLE_POWERON    260.0f // 上电后的初始目标角度
#define ANGLE_TOL        2.0f   // 到达目标的容差范围

// 采样与调度参数
#define SAMPLE_RATE      3200UL                   // 角度采样频率 (Hz)
#define SAMPLE_INTERVAL  (1000000UL / SAMPLE_RATE) // 采样间隔 (微秒)
#define FEEDBACK_INTERVAL 1000UL                  // 状态反馈间隔 (毫秒)
#define PID_INTERVAL     1000UL                   // PID计算间隔 (微秒)
#define CONFIRM_COUNT    5                        //  目标到达的确认次数（连续5次满足误差范围则判定到达）

// ================== 数据结构 ==================
// PID参数结构体
struct PIDParam {
  float kp, ki, kd; // PID控制参数，比例、积分、微分系数
};

// 传感器数据结构体
struct SensorData {
  float angle; // 滤波后的当前角度
  float rpm;   // 转速（由角度变化计算）
};

// 控制器状态结构体
struct ControlState {
  float target;        // 目标角度
  float error;         // 当前误差
  float integral;      // 误差积分项
  float derivative;    // 误差微分项
  float output;        // PID输出值（-100% 到 +100%）
  bool running;        // 控制器是否正在运行（电机是否激活）
  bool hold;           // 是否为“保持”模式（与普通定位模式参数不同）
  uint8_t arrivedCount;// 连续到达目标的次数，用于防抖
};

// 统计信息结构体
struct Stats {
  uint32_t loopCount, sampleCount;     // 总循环次数，总采样次数
  uint32_t lastLoopCount, lastSampleCount; // 用于计算每秒次数的上一次快照
};

// ================== 全局变量 ==================
Servo esc; // 创建Servo对象来控制电调
// PID参数：普通定位模式,需要自己调整
PIDParam pid = {0.7f, 0.0f, 0.047f};
// PID参数：保持模式（通常需要更柔和，防止震荡）
PIDParam pidHold = {0.01f, 0.0f, 0.0f};
// 传感器数据
SensorData sensor = {0,0};
// 控制器状态
ControlState ctrl = {-1,0,0,0,0,false,false,0};
// 统计信息
Stats stat = {0,0,0,0};

// 时间戳变量（用于任务调度）
uint32_t lastSampleMicros = 0; // 上一次采样的微秒时间
uint32_t lastPIDMicros    = 0; // 上一次PID计算的微秒时间
uint32_t lastFeedbackMs   = 0; // 上一次状态反馈的毫秒时间
uint32_t lastStatsMs      = 0; // 上一次统计信息输出的毫秒时间
float    lastAngle        = 0; // 上一次的角度值，用于计算转速

// 滑动中值滤波相关变量
#define FILTER_SIZE 7 // 滤波器窗口大小
float filterBuf[FILTER_SIZE] = {0}; // 滤波器缓冲区
uint8_t filterIdx = 0;              // 当前缓冲区索引
bool filterFilled = false;          // 缓冲区是否已填满一次

bool stopFlag = false;   // 全局停止标志

// ================== 函数声明 ==================
float readAngle();                  // 从AS5600读取原始角度
float medianFilter(float newVal);   // 中值滤波函数
float calcAngleDiff(float cur, float tgt); // 计算两个角度间的最短差值（考虑360度循环）
void pidControl(float dt);          // PID控制计算函数
void setTarget(float angle);        // 设置新的目标角度
void stopMotor();                   // 停止电机
void sendStatus();                  // 通过串口发送当前状态
void reportStats();                 // 报告性能统计
void parseCommand();                // 解析串口命令

// ================== 初始化 ==================
void setup() {
  Serial.begin(115200); // 初始化串口通信（波特率115200）
  Wire.begin();         // 初始化I2C总线
  Wire.setClock(400000); // 设置I2C时钟为400kHz，提高读取速度

  //电调初始化
  esc.attach(ESC_PIN);  // 将电调信号线连接到指定引脚
  esc.writeMicroseconds(PULSE_STOP); // 发送停止信号（常用于电调校准）
  delay(1000);          // 等待电调初始化

  Serial.println("=== AS5600 双向电调闭环系统 ===");
  Serial.println("指令: STOP | ANGLE xxx| PID kp ki kd | STATUS | STATS");
  //设置初始目标
  //setTarget(ANGLE_POWERON); // 系统启动后，默认转动到一个安全角度
}

// ================== 主循环 ==================
void loop() {
  stat.loopCount++; // 循环计数器递增
  uint32_t nowMicros = micros(); // 获取当前时间（微秒）
  uint32_t nowMillis = millis(); // 获取当前时间（毫秒）

  // --- 任务1：采样任务 (固定频率) ---
  if (nowMicros - lastSampleMicros >= SAMPLE_INTERVAL) {
    lastSampleMicros = nowMicros; // 更新最后一次采样时间
    stat.sampleCount++; // 采样计数器递增

    // 1. 读取原始角度值
    float raw = readAngle();
    // 2. 进行中值滤波，得到稳定的角度值
    sensor.angle = medianFilter(raw);

    // 3. 计算转速(RPM,基于角度变化率)
    //    计算距离上次采样的时间差（秒）
    float dt = (nowMicros - lastSampleMicros) / 1e6f;// 采样间隔（秒）
    if (dt > 0.0005f) { // 确保时间差有效，避免除零错误或过大误差
      float diff = sensor.angle - lastAngle; // 计算角度差
      // 处理角度跨越360°的边界情况，保证diff是两点间最短路径的差值,（例如：350度到10度的差应为20度，而非-340度）
      if (diff > 180) diff -= 360;
      else if (diff < -180) diff += 360;
      // 角度差(度)/时间(秒) * (60秒/分钟) / (360度/圈) = 转速(RPM)
      sensor.rpm = (diff / dt) * (60.0f / 360.0f);
      lastAngle = sensor.angle; // 更新“上一次的角度”
    }
  }

  // --- 任务2：PID控制任务 (固定频率) ---
  if (nowMicros - lastPIDMicros >= PID_INTERVAL) {
    float dt = (nowMicros - lastPIDMicros) / 1e6f; // 计算距离上次PID计算的时间差（秒）
    lastPIDMicros = nowMicros; // 更新最后一次PID计算时间
    if (ctrl.running) { // 只有控制器处于运行状态时才执行PID
      pidControl(dt);
    }
  }

  // --- 任务3：串口命令处理任务 (异步事件驱动,有数据时执行) ---
  if (Serial.available()) {
    parseCommand();
  }

  // --- 任务4：状态反馈任务 (固定间隔) ---
  if (nowMillis - lastFeedbackMs >= FEEDBACK_INTERVAL) {
    lastFeedbackMs = nowMillis;// 更新反馈时间戳
    sendStatus(); // 向串口发送当前角度、目标、状态等信息
  }

  // --- 任务5：性能统计任务 (固定间隔) ---
  if (nowMillis - lastStatsMs >= 1000) {
    lastStatsMs = nowMillis; // 更新统计时间戳
    reportStats(); // 向串口报告主循环和采样的频率
  }
}
// ================== 功能函数实现 ==================

// 从AS5600读取原始角度值
float readAngle() {
  Wire.beginTransmission(AS5600_ADDR); // 开始I2C传输，指定设备地址
  Wire.write(ANGLE_REG_H);             // 指定要读取的寄存器地址
  Wire.endTransmission(false);         // 发送重启信号（保持I2C连接有效）
  Wire.requestFrom(AS5600_ADDR, 2);    // 请求从设备读取2个字节
  if (Wire.available() < 2) return lastAngle; // 读取失败则，返回上次的角度值
  // 组合两个字节（高8位 + 低8位）成一个16位的原始值
  uint16_t raw = (Wire.read() << 8) | Wire.read();
  // 将原始值(0-4095)转换为角度值(0-359.9)
  return raw * 360.0f / 4096.0f;
}

// 中值滤波器：输入新值，返回滤波后的值
float medianFilter(float v) {
  // 将新值放入环形缓冲区
  filterBuf[filterIdx] = v;
  filterIdx = (filterIdx + 1) % FILTER_SIZE;
  // 检查缓冲区是否已被数据填满过一次
  if (!filterFilled && filterIdx == 0) filterFilled = true;

  // 创建临时数组进行排序
  float temp[FILTER_SIZE];
  // 确定当前有效数据的大小
  uint8_t size = filterFilled ? FILTER_SIZE : filterIdx;
  // 将有效数据拷贝到临时数组
  memcpy(temp, filterBuf, size * sizeof(float));

  // 使用插入排序对临时数组进行排序
  for (uint8_t i=1; i<size; i++){
    float key = temp[i];
    int j = i-1;
    while (j>=0 && temp[j] > key) {
      temp[j+1] = temp[j];
      j--;
    }
    temp[j+1] = key;
  }
  // 返回中值（排序后数组的中间值）
  return temp[size/2];
}

// // 计算当前角度到目标角度的最短路径差值（考虑360度循环）
// float calcAngleDiff(float cur, float tgt) {
//   float d = tgt - cur; // 直接差值
//   // 如果差值大于180度，说明反向走更短，例如：目标350，当前10 → 差应为-20（而非340）
//   if (d > 180) d -= 360;
//   // 如果差值小于-180度，说明正向走更短，例如：目标10，当前350 → 差应为20（而非-340）
//   else if (d < -180) d += 360;
//   return d;
// }
float constrainAngle(float angle) {
  // 将输入角度约束在安全范围
  if (angle < ANGLE_MIN) angle = ANGLE_MIN;
  if (angle > ANGLE_MAX) angle = ANGLE_MAX;
  return angle;
}
float calcAngleDiff(float current, float target) {
  target = constrainAngle(target);
  current = constrainAngle(current);
  float diff = target - current;
  if (diff > 180.0) diff -= 360.0;
  else if (diff < -180.0) diff += 360.0;
  return diff;
}

// PID控制计算函数
void pidControl(float dt) {
  // 1. 计算与目标的角度差（考虑360度循环）
  float diff = calcAngleDiff(sensor.angle, ctrl.target);
  float absDiff = fabs(diff); // 误差的绝对值

  // 2.  若未进入保持模式且误差在容忍范围内，计数确认到达目标
  if (!ctrl.hold && absDiff <= ANGLE_TOL) {
    // 如果误差在容差范围内，计数器加一
    if (++ctrl.arrivedCount >= CONFIRM_COUNT) {
      stopMotor(); // 连续多次到达，则认为真正到达，停止电机
      return;      // 退出本次PID计算
    }
  } else {
    // 如果误差变大或不在容差内，重置计数器
    ctrl.arrivedCount = 0;
  }

  // 3. 标准PID计算
  ctrl.error = diff; // 更新误差
  ctrl.integral += diff * dt; // 积分项累加
  ctrl.integral = constrain(ctrl.integral, -20.0f, 20.0f); // 积分限幅，防止积分饱和
  ctrl.derivative = (diff - ctrl.error) / dt; // 微分项

  // 4. 根据模式（定位/保持）选择PID参数并计算输出
  PIDParam &p = ctrl.hold ? pidHold : pid; // 选择参数集
  ctrl.output = p.kp * ctrl.error + p.ki * ctrl.integral + p.kd * ctrl.derivative;
  ctrl.output = constrain(ctrl.output, -100.0f, 100.0f); // 输出限幅到±100%

  // 5. 将PID输出（百分比）映射为电调能理解的脉冲宽度（微秒）
  int pulse;
  if (ctrl.output > 0) // 正转（输出为正）
    //pulse = map(ctrl.output, 0, 100, PULSE_FWD_MIN, PULSE_FWD_MAX);PULSE_FWD_MIN
    pulse = map(ctrl.output, 0, 100, PULSE_FWD_MIN, PULSE_FWD_MIN + 10);
  else if (ctrl.output < 0) // 反转（输出为负）
    //pulse = map(ctrl.output, 0, -100, PULSE_REV_MIN, PULSE_REV_MAX);
    pulse = map(ctrl.output, 0, -100, PULSE_REV_MIN, PULSE_REV_MIN - 10);
  else // 停止,输出为0（中立位置）
    pulse = PULSE_NEUTRAL;
  // 6. 将脉冲信号发送给电调
  esc.writeMicroseconds(pulse);
}

// 设置新的目标角度
void setTarget(float angle) {
  // 约束角度在安全范围内
  angle = constrain(angle, ANGLE_MIN, ANGLE_MAX);
  // 更新控制器状态
  ctrl.target = angle;
  ctrl.running = true;
  ctrl.hold = false; // 退出保持模式
  // 重置PID状态，防止历史数据影响新目标
  ctrl.integral = 0;
  ctrl.error = 0;
  ctrl.derivative = 0;
  ctrl.arrivedCount = 0;
  // 打印目标角度
  Serial.print("目标角度: ");
  Serial.println(angle, 1);
}

// 停止电机并重置控制状态
void stopMotor() {
  // 发送停止脉冲给电调
  esc.writeMicroseconds(PULSE_STOP);
  // 重置控制器状态
  ctrl.running = false;       // 停止控制
  ctrl.target = -1;           // 清除目标角度
  ctrl.integral = 0;          // 重置PID项
  ctrl.error = 0;
  ctrl.derivative = 0;
  ctrl.arrivedCount = 0;      // 重置到达计数
  ctrl.output = 0;            //重置电压输出值
  Serial.println("电机已停止");// 打印电机状态
}

// 通过串口发送状态信息
void sendStatus() {
  Serial.print("ANGLE:");
  Serial.print(sensor.angle, 2);// 当前角度
  Serial.print(",TARGET:");// 目标角度（-1表示无）
  // 如果目标无效（已停止）则显示-1，否则显示目标值
  Serial.print(ctrl.target < 0 ? -1 : ctrl.target, 2);
  Serial.print(",STATUS:");
  // 输出状态描述
  if (!ctrl.running)
    Serial.print("STOPPED");
  else if (fabs(calcAngleDiff(sensor.angle, ctrl.target)) <= ANGLE_TOL)
    Serial.print("TARGET"); // 已到达目标
  else
    Serial.print("MOVING"); // 正在移动
  Serial.print(",PID:");
  Serial.println(ctrl.output, 1); // PID输出值
}

// 报告性能统计（主循环频率和采样频率）
void reportStats() {
  uint32_t loops = stat.loopCount - stat.lastLoopCount;       // 过去1秒的循环次数
  uint32_t samples = stat.sampleCount - stat.lastSampleCount; // 过去1秒的采样次数
  stat.lastLoopCount = stat.loopCount;                        // 更新统计基准
  stat.lastSampleCount = stat.sampleCount;
  Serial.print("[Stats] Loop/s:");                            // 每秒循环次数
  Serial.print(loops);
  Serial.print(" Sample/s:");                                 // 每秒采样次数
  Serial.println(samples);
}

// 解析并执行从串口接收到的命令
void parseCommand() {
  static char buf[32]; // 静态缓冲区存储命令
  // 读取串口数据（直到换行符）
  uint8_t len = Serial.readBytesUntil('\n', buf, sizeof(buf) - 1);
  buf[len] = '\0'; // 手动添加字符串结束符

  // -----------【新增：去除末尾回车】-----------
  size_t n = strlen(buf);
  while (n > 0 && (buf[n - 1] == '\r' || buf[n - 1] == ' ')) {
    buf[--n] = '\0';
  }

  // -----------命令解析-----------
  if (strcasecmp(buf, "STOP") == 0) {
    stopMotor();             // 调用停止电机函数
    ctrl.running = false;    // 可选：标记系统已停止
    Serial.println("系统已停止");
    return;
  }

  if (strncasecmp(buf, "ANGLE", 5) == 0) {
    float a = atof(buf + 6); // 提取命令中的角度数值
    if (a >= ANGLE_MIN && a <= ANGLE_MAX)
      setTarget(a);
    else
      Serial.println("角度超出范围");
    return;
  }

  if (strcasecmp(buf, "HOLD") == 0) {
    ctrl.hold = true;
    ctrl.running = true; // 切换到保持模式
    Serial.println("保持模式");
    return;
  }

  if (strncasecmp(buf, "PID", 3) == 0) { // 设置PID参数命令（格式：PID kp ki kd）
    float kp, ki, kd;
    if (sscanf(buf + 3, "%f %f %f", &kp, &ki, &kd) == 3) {
      pid.kp = kp;
      pid.ki = ki;
      pid.kd = kd;
      Serial.print("PID设置: ");
      Serial.print(kp);
      Serial.print(" ");
      Serial.print(ki);
      Serial.print(" ");
      Serial.println(kd);
    } else {
      Serial.println("格式: PID kp ki kd");
    }
    return;
  }
  if (strcasecmp(buf, "STATUS") == 0) {
    sendStatus();
    return;
  }
  if (strcasecmp(buf, "STATS") == 0) {
    reportStats();
    return;
  }
  // 如果以上命令都不匹配
  Serial.println("未知命令");
}
